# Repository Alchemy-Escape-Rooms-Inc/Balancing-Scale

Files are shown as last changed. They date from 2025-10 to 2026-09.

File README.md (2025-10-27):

# BALANCING SCALE
A pendulum scale that is part of the pirate shiproom prop.
It is used to measure the weight of the different items in the puzzle.
The scale is using RFID technology to determine the pre-designated items
that are placed on the scale(plates), rather than measuring the actual weight. 
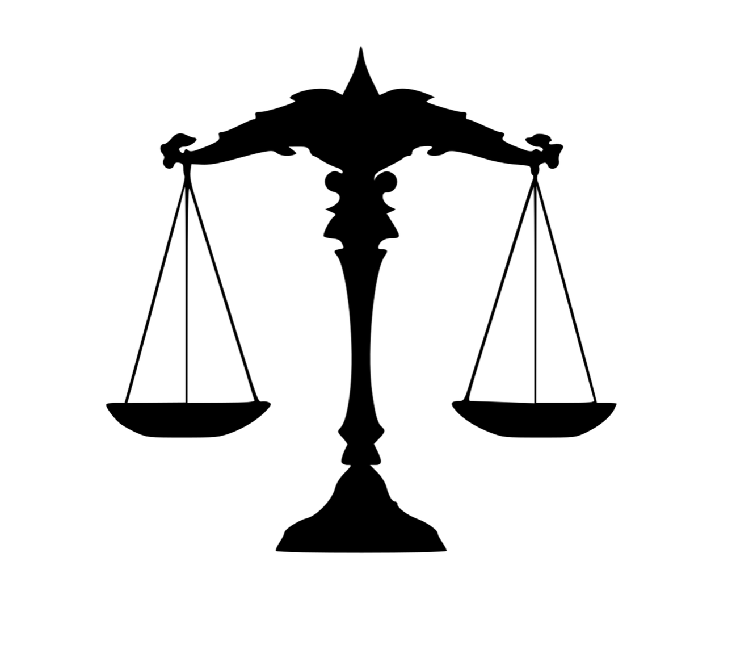
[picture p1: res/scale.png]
Scale


## RFID Readers
 The RFID readers used in this setup are two [ID-12LA](https://www.digikey.com/en/products/detail/sparkfun-electronics/11827/7364971); one for each plate. They are 125kHz RFID reader modules by ID-innovations and can be sourced most notibly from [DigiKey](https://www.Digikey.com) and [Sparkfun](https://www.sparkfun.com/).
The corresponding cards, stickers, fobs, etc. to be used with this reader must be 125kHz compatible to get a proper response from the reading module.
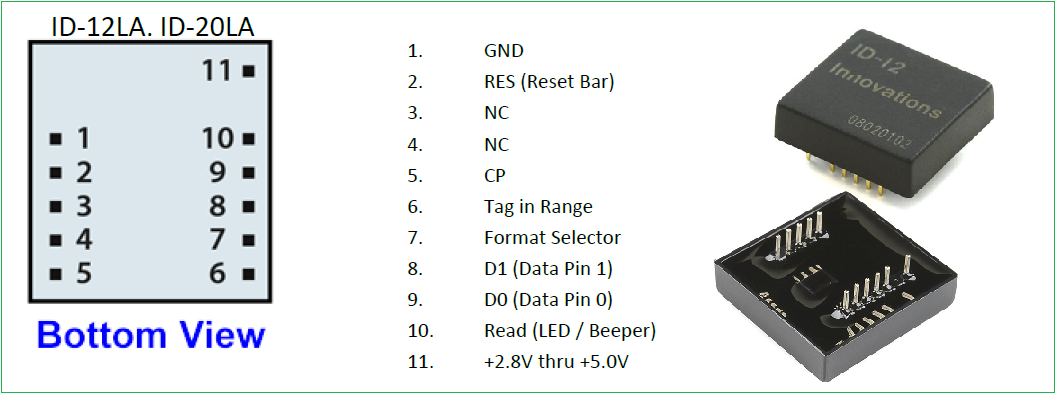
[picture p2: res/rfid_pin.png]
rfid


## Controller
The controller for this setup is the Arduino Nano. Its small compact size allow for it to conveniently be placed inside the scale's drawer. It is responsible for gathering and processing the information from the RFID readers.</br>
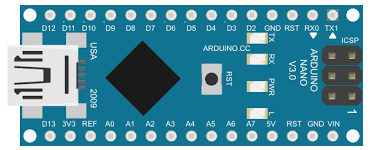
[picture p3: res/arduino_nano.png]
arduino


## Breakout Board
A custom printed circuit board that was designed to receive the 2mm pitch pins from the RFID reader and provide a few additional pins to connect with the reader.</br>
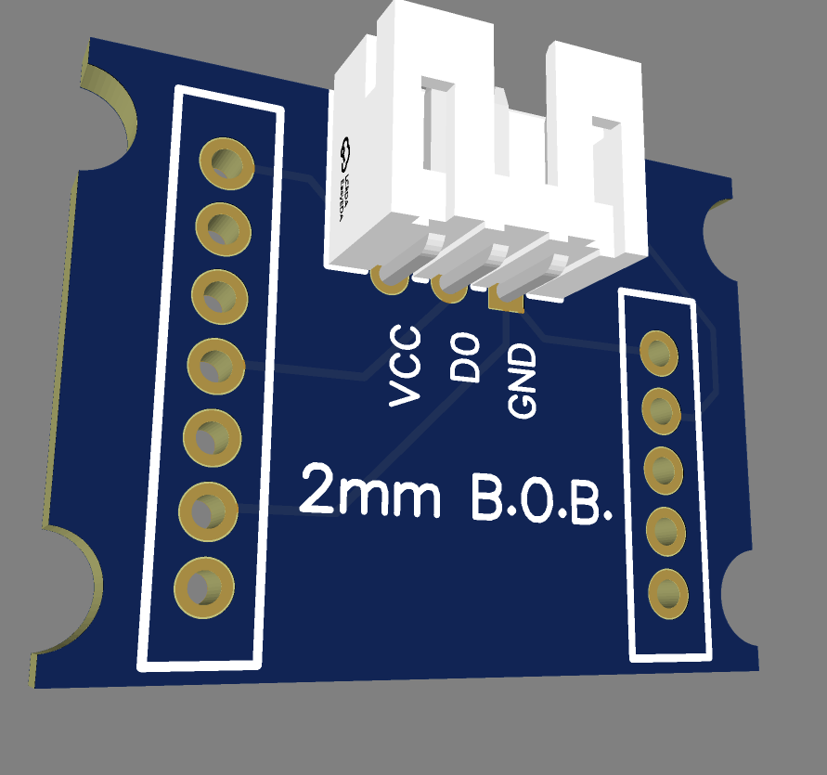
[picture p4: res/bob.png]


## 3D Models
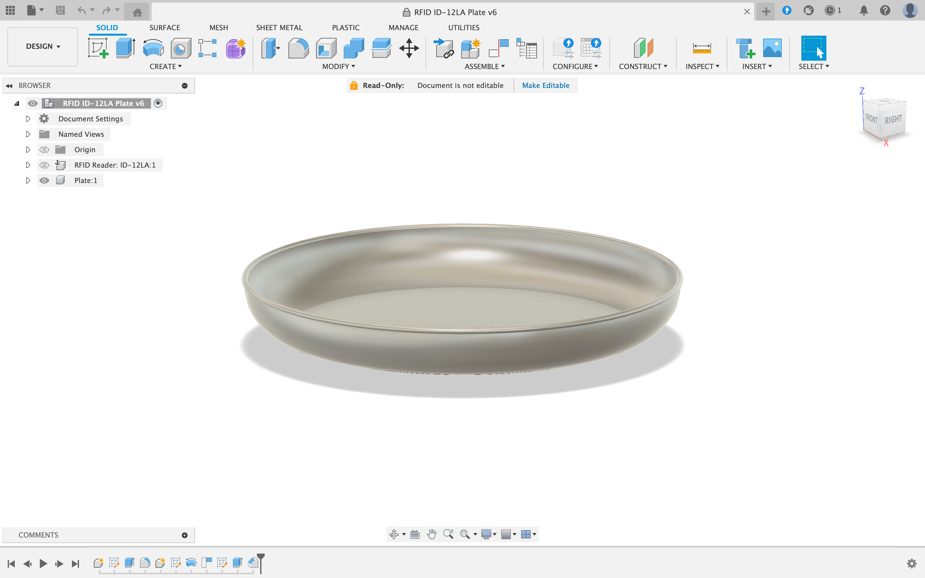
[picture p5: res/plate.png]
Plate
The RFID reader is uncapable of properly broadcasting a signal through metal plates; therefore a 3D model was designed to be used. Within the plate design, a guide for the RFID cover housing was attached underneath the plate. The RFID readers while being placed under the plates, should not be exposed, therefore a cover housing was designed. They are connected to the plate using screws.

## Algorithm
1. Plate 1 Listen for any rfid transmitter near by.
2. If there is no rfid being scanned, leave the sub routine. 
3. If there is a rfid in range, take the value and store 
it in a temporary variable. 
4. Check if the value is a valid pre-designated ID. 
5. If it is not a valid ID, leave the sub routine.
6. If it is a valid ID, check if it was already stored for 
the corresponding plate. 
7. If it was already stored, leave the sub routine. 
8. If it was not already stored, store the new ID for the 
corresponding plate.
9. Follow the same steps from 1-8 for plate 2. 
10. Check for any succession. 
11. If there was a succession, illuminate the green LED,
otherwise maintain the red LED.
12. Go back to step 1.

## Connections
There are a total of 3 modules in the Balancing Scale. Two rfid reader modules and an Arduino Nano. The ID-12LA rfid reader modules, is configured to output ASCII format via the D0 pin, when the FORMAT pin is tied to ground. The reset pin on the reader modules is tied to the supply voltage. The power connections (Vsupply and GND) to the rfid reader modules comes from the Arduino Nano. The D0 pins from the reader modules both get their own pin on the Arduino Nano. An RGB LED is added as an indicator. The red and green leads of the LED is tied via 1k resistors to the Arduino Nano. And, the final connection is the power to Arduino Nano comes in via the USB port.
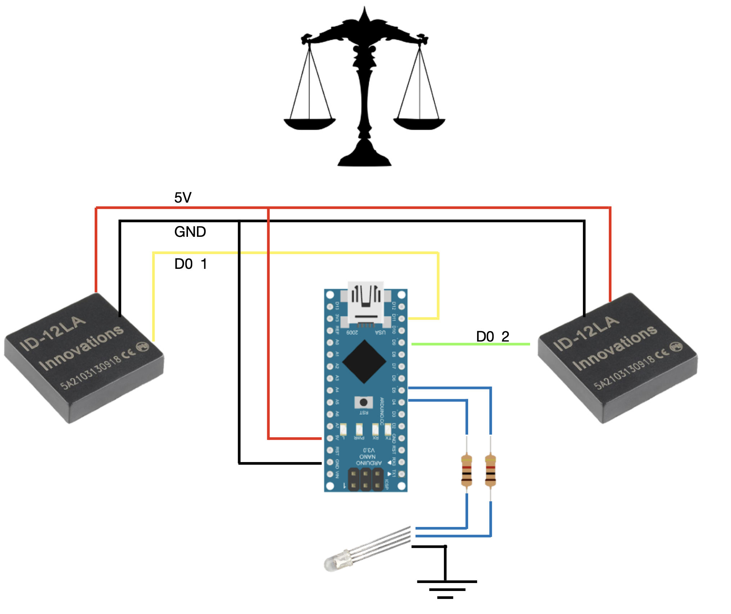
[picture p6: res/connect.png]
connections


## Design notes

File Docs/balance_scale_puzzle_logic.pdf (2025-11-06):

# Pirate Balancing Scale Puzzle

Logic Map & System Design

## Puzzle Overview

Players must balance five different spice pouches using gold coins of various denominations. The scale appears to be a traditional balance scale from the 1600s pirate era, but uses RFID technology to detect correct combinations. A compass indicator provides period-authentic feedback.

## Physical Components

Component | Description | Technology
Balance Scale | Two-plate traditional scale (theatrical) | Display prop
Spice Pouches | 5 pouches with different weights | RFID tags embedded
Gold Coins | 3 denominations with weights printed | RFID tags embedded
Compass Indicator | Points to "Aye" or "Nay" | Servo motor controlled
Left RFID Reader | Detects spice pouch | RC522 or PN532
Right RFID Reader | Detects coin combination | RC522 or PN532
ESP32 Controller | Processes logic and controls servo | ESP32-S3

## Weight Configuration

Spice Pouch | Weight | RFID Tag | Required Coins
Pouch 1 | 1.5g | Tag 112 | 1g + 0.5g or 0.75g + 0.75g
Pouch 2 | 1.75g | Tag 113 | 1g + 0.75g or 0.5g + 0.5g + 0.75g
Pouch 3 | 2.25g | Tag 114 | 1g + 1g + 0.25g or 0.75g + 0.75g + 0.75g
Pouch 4 | 3.5g | Tag 115 | 1g + 1g + 1g + 0.5g or various combos
Pouch 5 | 4.0g | Tag 116 | 1g + 1g + 1g + 1g
Coin Type | Weight | RFID Tag Range
Gold Doubloon | 1.0g | Tags 200-210

Half Doubloon | 0.5g | Tags 211-220
Piece of Eight | 0.75g | Tags 221-230
Quarter Doubloon | 0.25g | Tags 231-240

## System Logic Flow

1. System continuously monitors left RFID reader for spice pouch detection
2. When spice pouch is detected, system retrieves the target weight from lookup table
3. System continuously monitors right RFID reader for coin tags
4. System calculates total weight of detected coins based on their RFID tags
5. System compares calculated coin weight to required spice pouch weight
6. If weights match: Servo rotates compass from 'Nay' to 'Aye' position
7. If weights don't match: Compass remains at 'Nay' position
8. When spice pouch is removed from left reader: Servo resets compass to 'Nay' position
9. System returns to step 1 (ready for next attempt)

## System States

State | Condition | Compass Position | Action
IDLE | No spice pouch detected | Nay | Monitor left reader
DETECTING | Spice pouch on left | Nay | Monitor right reader & calculate
BALANCED | Correct coin combo | Aye | Hold until pouch removed
RESET | Pouch removed | Nay | Return to IDLE

## Hardware Connections

ESP32-S3 Pin Configuration:

Component | ESP32 Pin | Notes
Left RFID SDA | GPIO 21 | I2C or SPI depending on reader
Left RFID SCL | GPIO 22 | I2C or SPI clock
Right RFID SDA | GPIO 18 | Second I2C/SPI bus or different CS pin
Right RFID SCL | GPIO 19 | Second I2C/SPI clock
Servo Signal | GPIO 25 | PWM capable pin
Power (5V) | 5V | For RFID readers and servo

Ground | GND | Common ground for all components

## Programming Logic Overview

Data Structures:

Spice Pouch Lookup Table: Maps RFID tag IDs to weight values in grams

Coin Weight Lookup Table: Maps RFID tag ID ranges to coin weights

State Variables: Current spice pouch detected, calculated coin weight, compass position

Main Program Loop:

- Read left RFID reader for spice pouch tag
- If spice pouch detected:
- Look up required weight
- Read all tags from right RFID reader
- Calculate total weight of coins
- Compare weights
- Update compass position via servo
- If no spice pouch detected:
- Reset compass to 'Nay' position
- Delay 100-200ms before next loop iteration

## Compass Servo Control

Position | Angle | PWM Value | Meaning
Nay | 0° | ~1000µs pulse | Incorrect or no attempt
Aye | 90° | ~1500µs pulse | Correct balance achieved

## Player Experience Flow

1. Players discover five spice pouches and various gold coins with weights printed on them
2. Players place a spice pouch on the left side of the balance scale
3. Players experiment with different coin combinations on the right side

4. When correct total weight is achieved, compass dramatically spins to 'Aye'
5. Players note the successful combination and remove the spice pouch
6. Compass resets to 'Nay', ready for the next spice pouch
7. Players repeat process for all five spice pouches
8. Once all five combinations are discovered, the puzzle is complete

## Implementation Notes

- RFID readers should be concealed beneath or within the scale plates
- Servo motor should be hidden behind compass display
- Consider adding sound effects (creaking wood, wind) when compass moves
- Test RFID read range to ensure reliable detection through scale materials
- Multiple coins of same denomination should be supported (same weight, different tags)
- Consider adding a 'tolerance' margin if using actual weight sensors as backup
- Compass movement should be smooth and deliberate (not jerky) for theatrical effect
- System should debounce RFID readings to prevent flickering between states

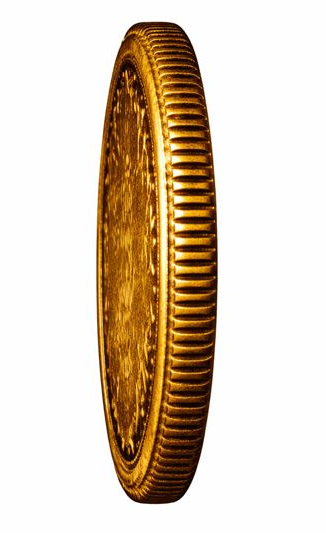
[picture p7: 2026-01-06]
3DFiles/2D/coins/side 1.png

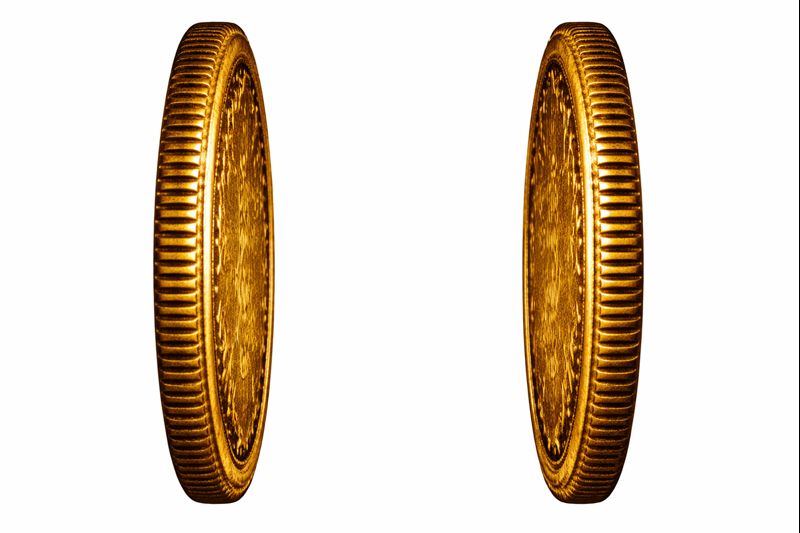
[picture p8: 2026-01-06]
3DFiles/2D/coins/sides.jpeg

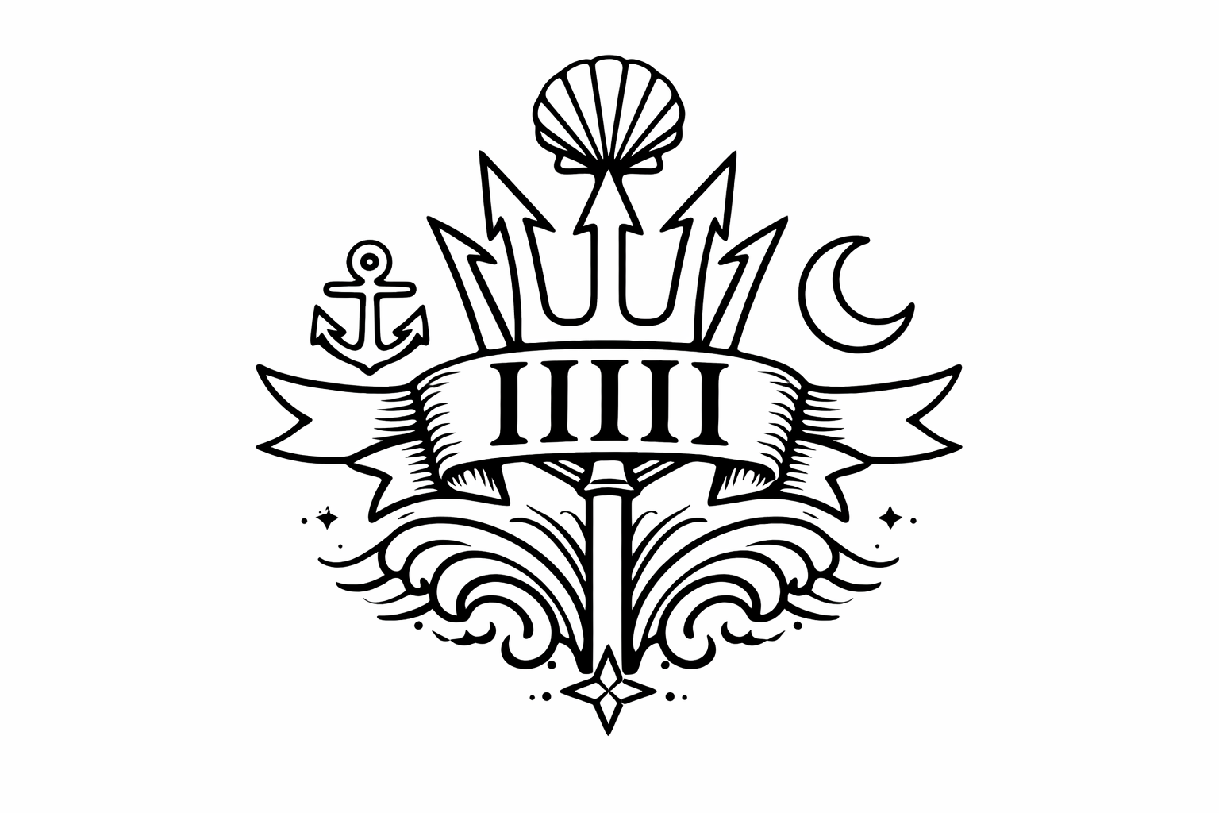
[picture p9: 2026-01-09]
3DFiles/2D/coins/generated/ChatGPT Image Jan 9, 2026, 08_28_24 AM.png

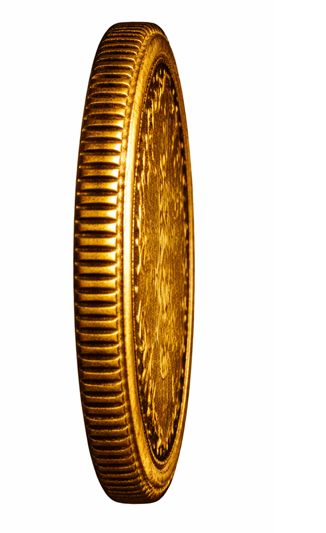
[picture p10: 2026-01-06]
3DFiles/2D/coins/side 2.png

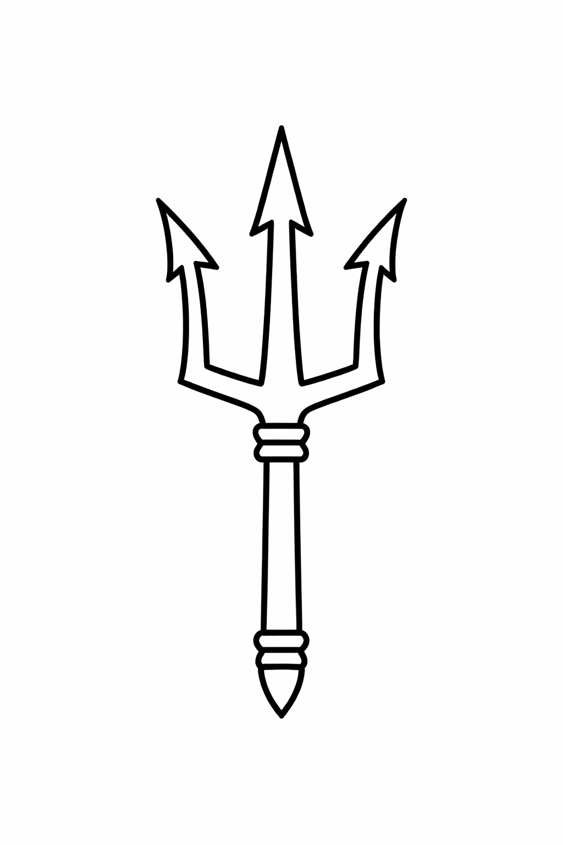
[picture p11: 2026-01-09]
3DFiles/2D/coins/generated/ChatGPT Image Jan 9, 2026, 08_28_42 AM.png

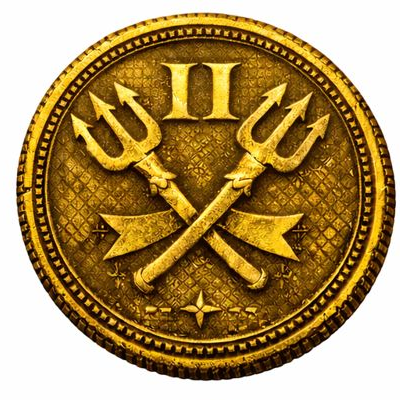
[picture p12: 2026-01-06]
3DFiles/2D/coins/Coin 2.png

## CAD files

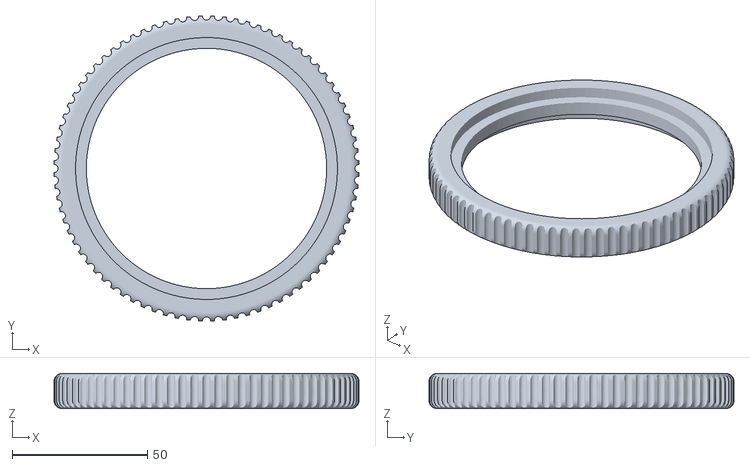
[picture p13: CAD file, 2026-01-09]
3DFiles/STL/Coins/Coin Ring.stl
113.0 x 113.0 x 13.0

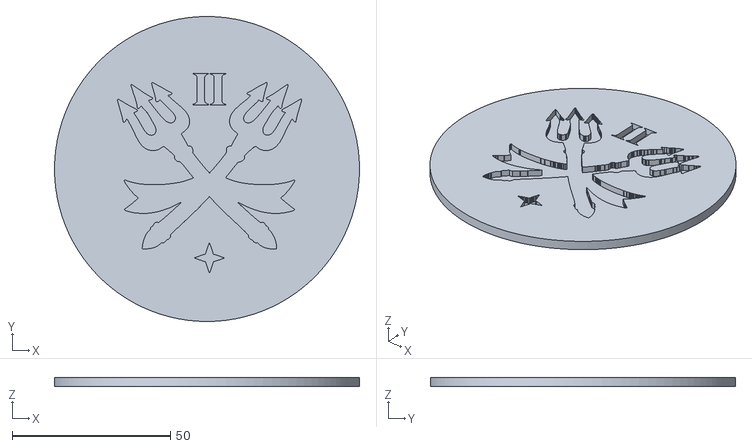
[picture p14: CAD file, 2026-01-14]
3DFiles/STL/Coins/v3/Crossing Tridents.stl
96.4 x 96.4 x 3.00

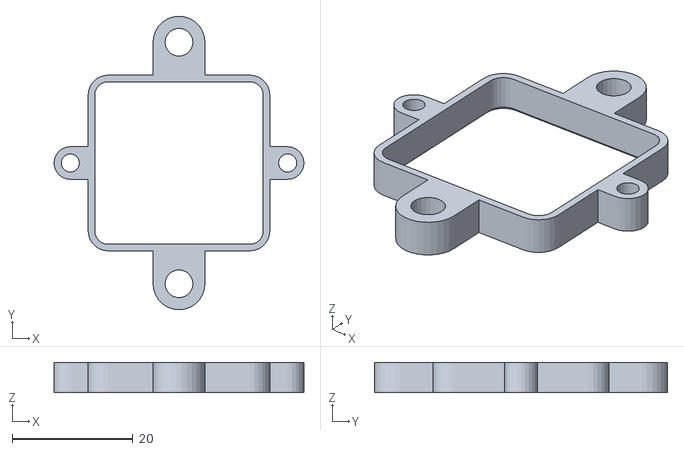
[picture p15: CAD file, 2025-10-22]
3DFiles/STL/RFID Reader/RFID ID-12LA Plate Mount.stl
41.4 x 48.6 x 5.00

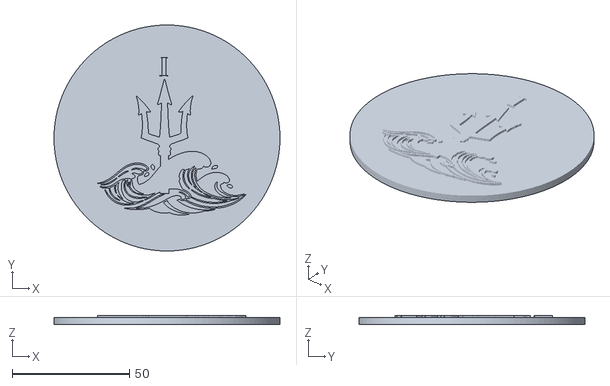
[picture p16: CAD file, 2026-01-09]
3DFiles/STL/Coins/Coins Face 1.stl
96.4 x 96.4 x 4.00

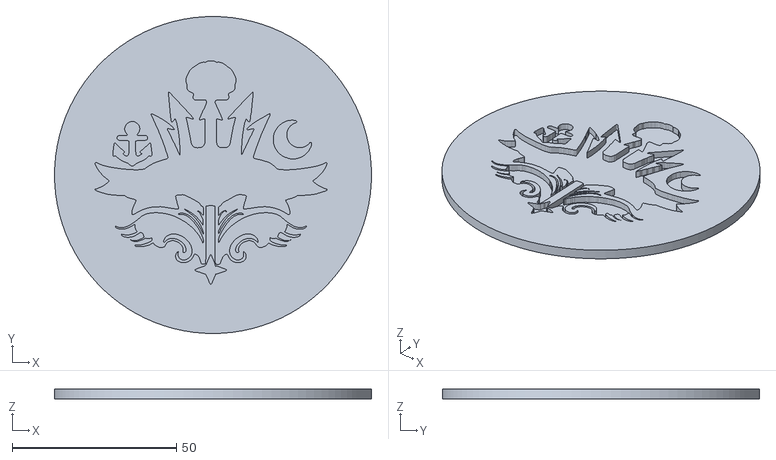
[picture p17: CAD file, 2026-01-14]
3DFiles/STL/Coins/v3/Emblem Trident.stl
96.4 x 96.4 x 3.00

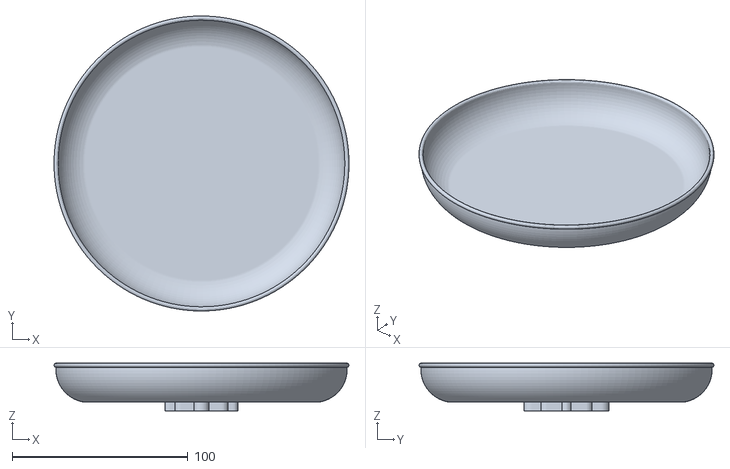
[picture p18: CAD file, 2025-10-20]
3DFiles/STL/RFID Reader/RFID ID-12LA Plate.stl
168.0 x 168.0 x 27.2

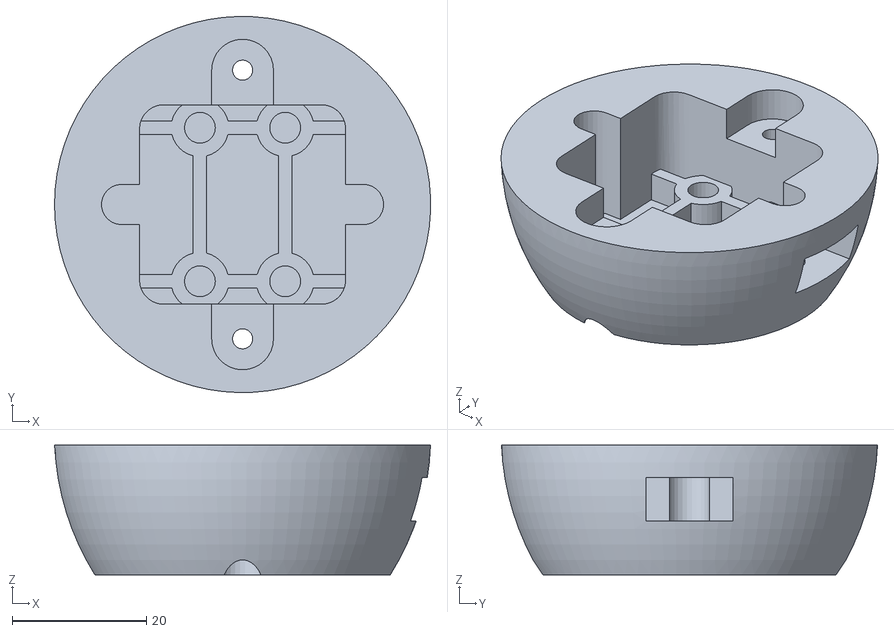
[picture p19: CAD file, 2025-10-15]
3DFiles/STL/RFID Reader/RFID ID-12LA Housing.stl
56.0 x 56.0 x 19.3

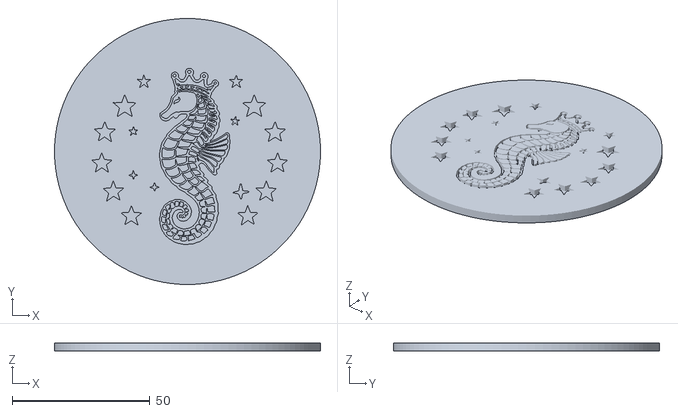
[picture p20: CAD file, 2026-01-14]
3DFiles/STL/Coins/v3/Seahorse.stl
96.4 x 96.4 x 3.00

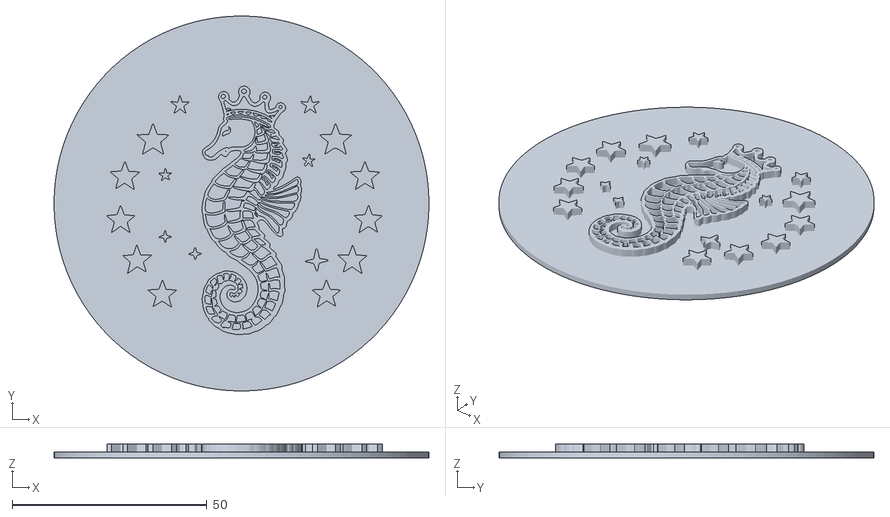
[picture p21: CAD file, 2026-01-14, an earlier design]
3DFiles/STL/Coins/v2/Seahorse.stl
96.4 x 96.4 x 3.50

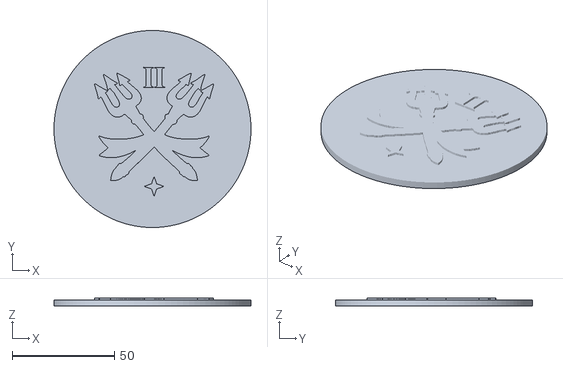
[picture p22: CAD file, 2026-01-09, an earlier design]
3DFiles/STL/Coins/v1/Coin Face 2.stl
96.4 x 96.4 x 4.00

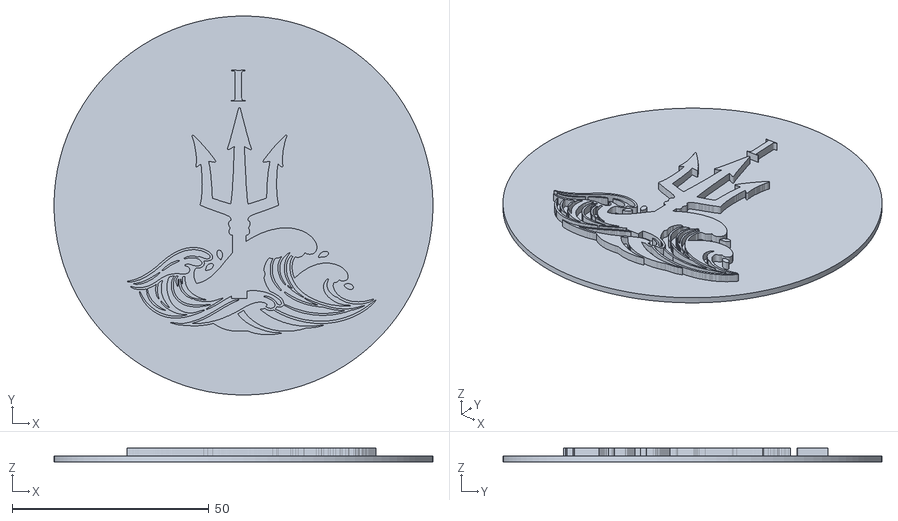
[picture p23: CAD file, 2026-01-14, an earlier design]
3DFiles/STL/Coins/v2/Waves Trident.stl
96.4 x 96.4 x 3.50

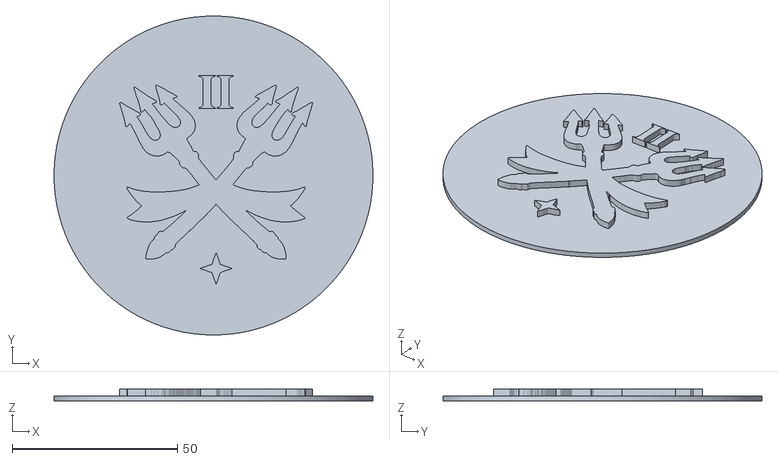
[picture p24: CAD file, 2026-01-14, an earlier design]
3DFiles/STL/Coins/v2/Crossing Trident.stl
96.4 x 96.4 x 3.50

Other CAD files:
3DFiles/STL/Coins/v3/Waves Trident.stl
3DFiles/STL/Coins/v3/Stars Trident.stl
3DFiles/STL/Coins/v1/Coin Face 4.stl
3DFiles/STL/Coins/v1/Coin Face 5.stl
3DFiles/STL/Coins/v2/Star Trident.stl
3DFiles/STL/Coins/v1/Coin Face 3.stl
3DFiles/Fusion360/RFID ID-12LA Housing.f3d
3DFiles/Fusion360/RFID ID-12LA Plate.f3d
3DFiles/STL/Coins/v2/Emblem Trident.stl

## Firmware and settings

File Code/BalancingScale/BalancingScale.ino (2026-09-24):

//=============================================================
//                        MACROS
//=============================================================
#pragma once

#include <WiFi.h>
#include <PubSubClient.h>
#include <HardwareSerial.h>
#include <ESP32Servo.h>
#include <ArduinoOTA.h>   // mandatory fleet protocol (2026-09-22): wireless re-flash

#define VERSION "1.4.0"

#define GAME_NAME "MermaidsTale"
#define PROP_NAME "BalancingScale"

#define MQTT_TOPIC          "MermaidsTale/BalancingScale"
#define MQTT_TOPIC_COMMAND  "MermaidsTale/BalancingScale/command"
#define MQTT_TOPIC_STATUS   "MermaidsTale/BalancingScale/status"
#define MQTT_TOPIC_LOG      "MermaidsTale/BalancingScale/log"
#define MQTT_TOPIC_MESSAGE  "MermaidsTale/BalancingScale/message"
#define MQTT_TOPIC_SYSTEM   "MermaidsTale/BalancingScale/system"


#define NUM_OF_SPICE_POUCHES 5
#define NUM_OF_COINS 8
#define SERVO_PIN 13

#define RX1 18
#define TX1 19

#define RX2 16
#define TX2 17
#define BAUD_RATE 115200
#define ID_LENGTH 4
#define MAX_READABLE 5                //RFIDs can only read 5 tags at once.

WiFiClient espClient;
PubSubClient mqttClient(espClient);
//=============================================================
//                      DATA STRUCTURE(S)
//=============================================================

/**
 * @brief A struct/container for holding a pair of values,
 *        the RFID(ID) and the represented weight.
 * @tparam N The maximum number of elements to
 *           represent the ID received from the RFID.
 */

template<byte N>
struct IDStorage {
  float weight;       //Represented weight of the RFID object.
  byte id[ID_LENGTH]; //ID of the RFID object.

  /**
   * @brief Default constructor, which initialize all values to 0.
   */
  IDStorage()
    : weight(0.0), id{ 0, 0, 0, 0 } {}
  /**
   * @brief Constructor, which initialize the members using
   *        the arguments.
   * @param vWeight Weight value to be assign to RFID the
   *                object.
   * @param &vID A constant array of char literals of size N.
   */
  IDStorage(float vWeight, const byte (&vID)[N])
    : weight(vWeight) {
      for (int i = 0; i < ID_LENGTH; i++)
        id[i] = vID[i];
    }

  /**
   * @brief Constructor, which initialize the members using
   *        the arguments.
   * @param vWeight Weight value to be assign to RFID object.
   * @param vID An array of char.
   */
  /*
     IDStorage(float vWeight,const char vID[]):weight(vWeight) {
     for (int i = 0; i < ID_LENGTH; i++)
     id[i] = vID[i];
     }
     */
};

//COINS
/**
 * @brief A derived struct of the IDStorage struct to
 *        hold values specifically for the RFID coins
 *        object demonations.
 * @tparam N The maximum number of elements to
 *           represent the ID received from the RFID.
 */
template<byte N>
struct Coin : IDStorage<N> {
  /**
   * @brief Constructor, which initialize the members using
   *        the arguments.
   * @param vWeight Weight value to be assign to the RFID
   *                object.
   * @param &vID A constant array of char literals of size N.
   */
  Coin(float vWeight, const byte (&vID)[N])
    : IDStorage<N>(vWeight, vID) {}
};

template<byte N>
struct GoldDoubloon : Coin<N> {
  GoldDoubloon(const byte (&vID)[N])
    : Coin<N>(1.0, vID) {}
};
template<byte N>
struct HalfDoubloon : Coin<N> {
  HalfDoubloon(const byte (&vID)[N])
    : Coin<N>(0.5, vID) {}
};
template<byte N>
struct PieceOfEight : Coin<N> {
  PieceOfEight(const byte (&vID)[N])
    : Coin<N>(0.75, vID) {}
};
template<byte N>
struct QuarterDoubloon : Coin<N> {
  QuarterDoubloon(const byte (&vID)[N])
    : Coin<N>(0.25, vID) {}
};

//POUCH
template<byte N>
struct Pouch : IDStorage<N> {
  String spice;
  Pouch(float vWeight, const byte (&vID)[N]):IDStorage<N>(vWeight, vID) {}
  Pouch(const String & vSpice, float vWeight, const byte (&vID)[N]):spice(vSpice),IDStorage<N>(vWeight, vID){}
};

//PLATES

/**
 * @brief A struct/container to hold a few values, for
 *        keeping track of the RFID objects placed on the
 *        scale's plates.
 * @tparam N The maximum number of IDs that can stored for
 *           this struct's object.
 */
template<byte N>
struct ScalePlates {
  IDStorage<ID_LENGTH> storage[N];  //An array of the IDs stored
  byte index = 0;                   //Value to keep track of the amount of stored IDs
  float plateWeight = 0.0;          //Represents the total amount of RFID objects placed on the scale's plate.

  /**
   * @brief Adds a new RFID object to the storage.
   * @param vWeight Weight value of the RFID object.
   * @param vID The ID of the RFID object.
   */
  void addNewStorage(float vWeight,const byte (&vID)[ID_LENGTH]){
    if((index + 1) > N)
      return;
    storage[index] = IDStorage<ID_LENGTH>(vWeight,vID);
    plateWeight += vWeight;
    index++;
  }

  /**
   * @brief Removes a RFID object from the storage.
   * @param rIndex Index of RFID object that is to be
   *               removed from the storage.
   */
  void removeStorage(int rIndex){
    if((index-1) < 0)
      return;
    float weight = storage[rIndex].weight;
    shiftStorageLeft(rIndex);
    clearStorage(index-1);
    plateWeight -= weight;
    index--;
  }

  /**
   * @brief Shifts all the RFID object information in
   *        the array storage to the left overriding
   *        one of stored objects.
   * @param sIndex Index of the stored object to be
   *               overriden by the left shift.
   */
  void shiftStorageLeft(int sIndex){
    for(int i = sIndex; i < index; i++){
      for(int j = 0; j < ID_LENGTH; j++){
        if((i + 1) != index)
          storage[i].id[j] = storage[i+1].id[j];
      }
      if((i + 1) != index)
        storage[i].weight = storage[i+1].weight;
    }
  }

  /**
   * @brief Clears/Sets all the RFID object information
   *        to 0.
   * @param cIndex Index of the stored object information
   *               to be cleared.
   */
  void clearStorage(int cIndex){
    for(int i  = 0; i < ID_LENGTH; i++)
      storage[cIndex].id[i] = 0;
    storage[cIndex].weight = 0.0;
  }


  void printStorage(){

    //if(index <= 0)
    //  return;
    /*
       for(int i = 0; i < index; i++){

       String uid = "";
       for(int j = 0; j < ID_LENGTH; j++)
       uid += String(storage[i].id[j],HEX) + String((j == ID_LENGTH-1) ? "":"-");

       mqttClient.publish(String(String(MQTT_TOPIC_SYSTEM) + "/storedUID" + String(i)).c_str(),uid.c_str());

       }
       */
    mqttClient.publish(String(String(MQTT_TOPIC_SYSTEM) + "/storedWeight").c_str(),String(plateWeight).c_str());
    mqttClient.publish(String(String(MQTT_TOPIC_SYSTEM) + "/storedIndex").c_str(),String(index).c_str());
  }
};

//=============================================================
//                      GLOBAL VARIABLES
//=============================================================

byte CMD_GET_TAG_COUNT[] = { 0xF5, 0x03, 0x00, 0xFC, 0xFF, 0x02, 0xB2, 0xC1 };
byte CMD_HALT[] = { 0xF5, 0x03, 0x00, 0xFC, 0xFF, 0x05, 0x55, 0xB1 };
byte CMD_REBOOT[] = { 0xF5, 0x03, 0x00, 0xFC, 0xFF, 0x0A, 0xBA, 0x40 };
byte CMD_DUMMY[] = { 0xF5, 0x03, 0x00, 0xFC, 0xFF, 0x01, 0xD1, 0xF1 };
byte CMD_GET_UID[5][9] = {
  { 0xF5, 0x04, 0x00, 0xFB, 0xFF, 0x03, 0x00, 0x5C, 0x48 },
  { 0xF5, 0x04, 0x00, 0xFB, 0xFF, 0x03, 0x01, 0x7D, 0x58 },
  { 0xF5, 0x04, 0x00, 0xFB, 0xFF, 0x03, 0x02, 0x1E, 0x68 },
  { 0xF5, 0x04, 0x00, 0xFB, 0xFF, 0x03, 0x03, 0x3F, 0x78 },
  { 0xF5, 0x04, 0x00, 0xFB, 0xFF, 0x03, 0x04, 0xD8, 0x08 }
};

Servo mServo;
HardwareSerial rfid1(1);
HardwareSerial rfid2(2);



byte uid[ID_LENGTH * MAX_READABLE];


const char* WIFI_SSID = "AlchemyGuest";
const char* WIFI_PASS = "VoodooVacation5601";
const char* OTA_PASSWORD = WIFI_PASS;   // protocol: OTA password = Wi-Fi password
#define OTA_HOSTNAME PROP_NAME          // protocol: hostname = DEVICE_NAME
#define OTA_PORT     3232               // classic ESP32 default

// MQTT broker
const char* MQTT_SERVER = "10.1.10.115";
const int MQTT_PORT = 1883;

bool servoState = false;    //true = yay, false = nay

float weights[5];     //array to hold the spices weight
bool success[5] = {false,false,false,false,false}; //array for tracking the correct spice pouch solved

bool puzzleSolved = false;

String incoming = "";


const unsigned long heartBeatPulse = 300 * 1000UL;  //heart beat for MQTT, every 5 minutes (WatchTower standard)
const unsigned long scanPeriod = 1000UL;      //scanning of the RFIDs and other associated operations, every second

unsigned long hLastTime = 0;
unsigned long sLastTime = 0;

//Known IDs for the pouches and their represented weights.
const Pouch<ID_LENGTH> sPouches[NUM_OF_SPICE_POUCHES] = {

  Pouch<ID_LENGTH>("Yeast",2.5f, (byte []){0xC1, 0x27, 0xFB,0x19}),
  Pouch<ID_LENGTH>("SugarCane",2.25f,  (byte []){0x60, 0x74, 0x15,0x21}),
  Pouch<ID_LENGTH>("Vanilla",1.75f,  (byte []){0x94, 0xD3, 0xC9,0x1}),
  Pouch<ID_LENGTH>("Molasses",2.75f,  (byte []){0x80, 0x1E, 0x7C,0x21}),
  Pouch<ID_LENGTH>("Cloves",1.5f,  (byte []){0x71, 0xD, 0xEB,0x17})
};

//Known IDs for the coins and their represented weights.
//ROOM NAMES (owner, 2026-09-10) - the players' rules call these coins:
//  GoldDoubloon    = "gold"   = 1.00
//  PieceOfEight    = "silver" = 0.75   (NOT a historical piece of eight - a puzzle value)
//  HalfDoubloon    = "copper" = 0.50
//  QuarterDoubloon = "bronze" = 0.25
//The struct names below are the contractor's; the values are what the scale
//checks. Two coins of each type. A plate reads at most MAX_READABLE tags.
const Coin<ID_LENGTH> coins[NUM_OF_COINS] = {
  //example of initialization of coins
  GoldDoubloon<ID_LENGTH>({0x80, 0xD5, 0xCF,0x21}),
  GoldDoubloon<ID_LENGTH>({0x31, 0x61, 0x86,0x26}),
  HalfDoubloon<ID_LENGTH>({0x1B,0xF,0x39,0x6}),
  HalfDoubloon<ID_LENGTH>({0x19,0xF0,0x4F,0x6}),
  PieceOfEight<ID_LENGTH>({0x81,0xE8,0x50,0x6}),
  PieceOfEight<ID_LENGTH>({0xF1,0x76,0xC3,0x1}),
  QuarterDoubloon<ID_LENGTH>({0xE2,0x52,0xE3,0x19}),
  QuarterDoubloon<ID_LENGTH>({0x62,0xC7,0x38,0x6})
};

//Objects to store the detected tag IDs based on their type.
ScalePlates<NUM_OF_COINS> coinsPlate;
ScalePlates<NUM_OF_SPICE_POUCHES> pouchesPlate;

//=============================================================
//                    NETWORK & MQTT
//=============================================================

//WIFI NETWORK
void setupWiFi() {
  delay(1000);
  Serial.println("*********** WIFI ***********");
  Serial.print("Connecting to SSID: ");
  Serial.println(WIFI_SSID);

  WiFi.begin(WIFI_SSID,WIFI_PASS);

  while(WiFi.status() != WL_CONNECTED){
    delay(100);
    Serial.print("-");
  }
  Serial.println("\nConnected.");
  Serial.print("IP: "); Serial.print(WiFi.localIP());
  Serial.print("  GW: "); Serial.print(WiFi.gatewayIP());
  Serial.print("  RSSI: "); Serial.println(WiFi.RSSI());
}

/**
 * @brief Over-the-air update listener (fleet protocol, mandatory since
 *        2026-09-22). hostname = BalancingScale, port 3232, password = Wi-Fi.
 *        Flash wirelessly with:
 *          arduino-cli upload --fqbn esp32:esp32:esp32 -p <board IP>
 *              --upload-field password=<Wi-Fi pw> Code/BalancingScale
 *        The IP is in every STATUS reply and the boot line on /log.
 *        No task WDT on this board, so nothing to feed during upload.
 */
void setupOTA() {
  ArduinoOTA.setHostname(OTA_HOSTNAME);
  ArduinoOTA.setPassword(OTA_PASSWORD);
  ArduinoOTA.onStart([]() {
    // Only actuator is the indicator servo - park it so it is not mid-swing
    // on the reboot. Readers just stop being polled.
    servoMid();
    mqttLogf("OTA update starting - scale holds, back in ~30 s");
    mqttClient.loop();
  });
  ArduinoOTA.onEnd([]()   { Serial.println("OTA done, rebooting"); });
  ArduinoOTA.onError([](ota_error_t e) { Serial.printf("OTA error %u\n", (unsigned)e); });
  ArduinoOTA.begin();
  Serial.printf("OTA ready: %s @ %s:%d\n", OTA_HOSTNAME, WiFi.localIP().toString().c_str(), OTA_PORT);
}

//MQTT SERVER
void connectMQTT() {
  while (!mqttClient.connected()) {
    Serial.print("Connecting to MQTT...");

    String clientId = PROP_NAME;
    clientId += "_";
    clientId += String(random(0xffff), HEX);

    // LWT: broker publishes retained OFFLINE on /status if we drop
    if (mqttClient.connect(clientId.c_str(), MQTT_TOPIC_STATUS, 1, true, "OFFLINE")) {
      Serial.println("connected!");

      // Subscribe to command topic
      mqttClient.subscribe(MQTT_TOPIC_COMMAND);

      // Announce we're online
      mqttClient.publish(MQTT_TOPIC_STATUS, "ONLINE", true);
      mqttLogf("%s v%s online IP:%s OTA:%d RSSI:%d", PROP_NAME, VERSION,
               WiFi.localIP().toString().c_str(), OTA_PORT, WiFi.RSSI());

    } else {
      Serial.printf("failed (rc=%d), retrying in 5s\n", mqttClient.state());
      // Keep the OTA listener alive while the broker is down so a bad
      // build that cannot reach MQTT can still be replaced wirelessly.
      for (int i = 0; i < 50; i++) { ArduinoOTA.handle(); delay(100); }
    }
  }
}

void mqttCallback(char* topic, byte* payload, unsigned int length) {
  char topicBuf[128];
  strncpy(topicBuf,topic,sizeof(topicBuf)-1);
  topicBuf[sizeof(topicBuf)-1] = '\0';

  char message[128];
  if(length >= sizeof(message)){
    length = sizeof(message) - 1;
  }

  memcpy(message,payload,length);
  message[length] = '\0';

  char * msg = message;
  while(*msg == ' ' || *msg == '\r' || *msg == '\n')
    msg++;
  char * end = msg + strlen(msg) -1;
  while(end > msg && (*end == ' ' || *end == '\t' || *end == '\r' || *end == '\n')){
    *end = '\0';
    end--;
  }

  //Serial.printf("[MQTT] Received on %s: %s\n", topicBuf,msg);

  if(strcmp(topicBuf,MQTT_TOPIC_COMMAND) != 0){
    return;
  }

  // Our own PONG/OK replies arrive back on /command (we subscribe to it).
  // Ignore them silently so they don't register as unknown commands.
  if(strcmp(msg,"PONG") == 0 || strcmp(msg,"OK") == 0 || strlen(msg) == 0){
    return;
  }

  if(strcmp(msg,"PING") == 0){
    // WatchTower standard: PONG on the topic the command arrived on
    mqttClient.publish(MQTT_TOPIC_COMMAND,"PONG");
    return;
  }
  if(strcmp(msg,"STATUS") == 0){
    publishDiagnostics();
    return;
  }
  if(strcmp(msg,"RESET") == 0){
    // WatchTower standard: respond OK, then software reboot
    mqttLogf("RESET: rebooting");
    mqttClient.publish(MQTT_TOPIC_COMMAND,"OK");
    mqttClient.loop();
    delay(250);
    ESP.restart();
    return;
  }
  if (strcmp(msg, "PUZZLE_RESET") == 0) {
    // Reset game state without rebooting
    puzzleReset();
    mqttClient.publish(MQTT_TOPIC_COMMAND, "OK");
    return;
  }
  if (strcmp(msg, "SOLVE") == 0) {
    // GM override: mark the puzzle solved
    puzzleSolved = true;
    updateServo(true);
    publishSolved();
    return;
  }

  if (strcmp(msg, "HALTCOIN") == 0) {
    haltReader(rfid2);
    mqttClient.publish(MQTT_TOPIC_MESSAGE, "Halting coins' plate rfid field.");
    return;
  }
  if (strcmp(msg, "HALTSPICE") == 0) {
    haltReader(rfid1);
    mqttClient.publish(MQTT_TOPIC_MESSAGE, "Halting spices' plate rfid field.");
    return;
  }
  if (strcmp(msg, "REBOOTCOIN") == 0) {
    rebootReader(rfid2);
    mqttClient.publish(MQTT_TOPIC_MESSAGE, "Rebooting coins' plate rfid.");
    delay(1000); //needs minimum 1 second boot time
    return;
  }
  if (strcmp(msg, "REBOOTSPICE") == 0) {
    rebootReader(rfid1);
    mqttClient.publish(MQTT_TOPIC_MESSAGE, "Rebooting spices' plate rfid.");
    delay(1000); //needs minimum 1 second boot time
    return;
  }
  mqttLogf("Unknown command: %s", msg);
}

/**
 * @brief Publishes SOLVED on /status. M3's "Balancing Scale Solved" event
 *        matches this exact payload and forwards MermaidsTale/ScaleSolved.
 *        Not retained: a retained SOLVED would replay into fresh sessions.
 */
void publishSolved(){
  mqttClient.publish(MQTT_TOPIC_STATUS, "SOLVED");
  mqttLogf("PUZZLE SOLVED");
}

/**
 * @brief Resets all game state without rebooting (PUZZLE_RESET).
 */
void puzzleReset(){
  puzzleSolved = false;
  for(int i = 0; i < 5; i++)
    success[i] = false;
  clearAllParameters();
  updateServo(false);
  mqttClient.publish(MQTT_TOPIC_STATUS, "ONLINE", true);
  mqttLogf("PUZZLE_RESET complete");
}

/**
 * @brief Publishes a full diagnostics string on /status (STATUS command).
 */
void publishDiagnostics(){
  int count = 0;
  for(int i = 0; i < 5; i++)
    if(success[i])
      count++;
  char diag[192];
  snprintf(diag, sizeof(diag),
    "%s v%s | State=%s | Spice=%.2f | Coins=%.2f | Matched=%d/5 | IP:%s | OTA:%d | RSSI=%d | UP%lus",
    PROP_NAME, VERSION,
    puzzleSolved ? "SOLVED" : "ONLINE",
    pouchesPlate.plateWeight, coinsPlate.plateWeight, count,
    WiFi.localIP().toString().c_str(), OTA_PORT, WiFi.RSSI(), millis() / 1000UL);
  mqttClient.publish(MQTT_TOPIC_STATUS, diag);
}

void setupMQTT() {
  mqttClient.setServer(MQTT_SERVER, MQTT_PORT);
  mqttClient.setCallback(mqttCallback);
  mqttClient.setBufferSize(512);  // Increase if needed
}

void heartBeat(){
  unsigned long currentTime = millis();
  if(!(currentTime - hLastTime > heartBeatPulse))
    return;
  hLastTime = currentTime;
  // WatchTower standard heartbeat format on /status
  char hb[64];
  snprintf(hb, sizeof(hb), "HEARTBEAT:%s:UP%lus:RSSI%d",
           puzzleSolved ? "SOLVED" : "ONLINE", millis() / 1000UL, WiFi.RSSI());
  mqttClient.publish(MQTT_TOPIC_STATUS, hb);
  // While solved, re-assert the plain SOLVED payload M3 matches on, in case
  // M3 restarted mid-game and missed the live solve event.
  if(puzzleSolved)
    mqttClient.publish(MQTT_TOPIC_STATUS, "SOLVED");
}

void mqttLogf(const char* format, ...) {
  char buffer[256];
  va_list args;
  va_start(args, format);
  vsnprintf(buffer, sizeof(buffer), format, args);
  va_end(args);

  mqttClient.publish(MQTT_TOPIC_LOG, buffer);
  //Serial.println(buffer);
}

//=============================================================
//                  MAIN FUNCTIONS
//=============================================================
//=============================================================
//                  MISC FUNCTIONS
//=============================================================

void setupServo(){
  mServo.setPeriodHertz(100);
  mServo.attach(SERVO_PIN, 500, 2400); 
}

/**
 * @brief This function rotates the angle to
 *        0 degrees. Representing Yay.
 */
void servoYay(){
  mqttClient.publish(String(String(MQTT_TOPIC_MESSAGE) + "/servo").c_str(),"yay");
  mServo.write(155);
}
/**
 * @brief This function rotates the angle to
 *        90 degrees. Representing Nay.
 */
void servoNay(){
  mqttClient.publish(String(String(MQTT_TOPIC_MESSAGE) + "/servo").c_str(),"nay");
  mServo.write(30);
}



void updateServo(bool state){
  if(state){
    if(state == servoState){
      return;
    }
    else{
      servoYay();
      servoState = state;
    }

  } else {

    if(state == servoState){
      return;
    }
    else{
      servoNay();
      servoState = state;
    }
  }
 mqttClient.publish(String(String(MQTT_TOPIC_MESSAGE) + "/ServoState").c_str(),(state) ? "true":"false");
}
void servoMid(){
   mqttClient.publish(String(String(MQTT_TOPIC_SYSTEM) + "/servo").c_str(),"center");
   mServo.write(70);
}
/**
 * @brief This function resets all the scale's stored
 *        data.
 */
void clearAllParameters(){
  for(int i = 0; i < coinsPlate.index; i++)
    coinsPlate.clearStorage(i);
  for(int i = 0; i < pouchesPlate.index; i++)
    pouchesPlate.clearStorage(i);

  coinsPlate.plateWeight = 0.0;
  pouchesPlate.plateWeight = 0.0;

  coinsPlate.index = 0;
  pouchesPlate.index = 0;
}

/**
 * @brief This function checks if the user has success
 *        balanced the weight with the items.
 */
void checkSuccess(){
  //no tags on a plate, or weights don't match: show nay and leave.
  //(only touch the servo here on an actual mismatch — writing nay
  //unconditionally made the servo flap nay->yay every scan while balanced)
  if(pouchesPlate.plateWeight == 0 || coinsPlate.plateWeight == 0
     || pouchesPlate.plateWeight != coinsPlate.plateWeight){
    updateServo(false);
    return;
  }

  //weights match, update servo to yay
  updateServo(true);

  //get the matching weight and update the success tracking array
  //(publish the per-pouch topic once, on the transition - not every scan)
  bool newSuccess = false;
  for(int i = 0; i < 5; i++){
    if(weights[i] == pouchesPlate.plateWeight && !success[i]){
      success[i] = true;
      newSuccess = true;
      printSuccessToMQTT(i);
    }
  }

  //count the successes
  int count = 0;
  for(int i = 0; i < 5; i++)
    if(success[i])
      count++;

  if(newSuccess)
    mqttClient.publish(String(String(MQTT_TOPIC_MESSAGE) + "/SuccessCount").c_str(),String(count).c_str());
  //if success count is 5, the prop puzzle is solved, and finished
  if(count >= 5 && !puzzleSolved){
    puzzleSolved = true;
    publishSolved();
  }
}

/**
 * @brief Verify if the array of chars are a match.
 *
 * This function verifies if the passed in IDs are
 * identical.
 *
 * @param id1 An array of char representing the RFID(ID).
 * @param id2 An array of char representing the RFID(ID).
 * @return A boolean value, whether both IDs are identical.
 */
bool isAMatchingID(const byte id1[], const byte id2[]) {
  for (int i = 0; i < ID_LENGTH; i++)
    if (id1[i] != id2[i])
      return false;
  return true;
}
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
void loop() {
  program();
}

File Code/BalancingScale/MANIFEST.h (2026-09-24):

// ============================================================
// MANIFEST.h — WatchTower Device Manifest
// This file is parsed by sync_manifests.py for the WatchTower dashboard.
// Keep all values as #define strings unless noted otherwise.
// ============================================================

#define DEVICE_NAME           "BalancingScale"
#define FIRMWARE_VERSION      "1.4.0"
#define BOARD_TYPE            "ESP32 (classic, CP210x USB bridge)"
#define ROOM                  "MermaidsTale"
#define DESCRIPTION           "RFID pendulum scale: two multi-tag RFID readers (spice pouches vs coins plates) match represented weights; servo indicates balance; publishes SOLVED on /status when all 5 pouch weights have been matched (M3 forwards as MermaidsTale/ScaleSolved)"

#define BUILD_STATUS          "stable"
#define CODE_HEALTH           "fair"
#define WATCHTOWER_COMPLIANCE "full"

// MQTT
#define BROKER_IP             "10.1.10.115"
#define BROKER_PORT           1883
#define HEARTBEAT_MS          300000

// Over-the-air updates (MANDATORY fleet protocol since 2026-09-22, added v1.4.0).
// Password = the Wi-Fi password (OTA_PASSWORD aliases WIFI_PASS in the sketch).
#define OTA_ENABLED           "yes"
#define OTA_HOSTNAME          "BalancingScale"      // = DEVICE_NAME
#define OTA_PORT              3232                  // classic ESP32

#define SUBSCRIBE_TOPICS      "MermaidsTale/BalancingScale/command"
#define PUBLISH_TOPICS        "MermaidsTale/BalancingScale/status, MermaidsTale/BalancingScale/log, MermaidsTale/BalancingScale/message, MermaidsTale/BalancingScale/message/servo, MermaidsTale/BalancingScale/message/Spice, MermaidsTale/BalancingScale/system/Spice/weight, MermaidsTale/BalancingScale/system/Coins/weight, MermaidsTale/BalancingScale/message/SuccessCount, MermaidsTale/BalancingScale/message/ServoState, MermaidsTale/BalancingScale/{Yeast|SugarCane|Vanilla|Molasses|Cloves}"
#define SUPPORTED_COMMANDS    "PING, STATUS (reply ... | IP:x.x.x.x | OTA:3232 | RSSI=x | UPxs), RESET, PUZZLE_RESET, SOLVE, HALTCOIN, HALTSPICE, REBOOTCOIN, REBOOTSPICE"

// Hardware
#define PIN_CONFIG            "SERVO=13 (was 35 = input-only on classic ESP32; moved by contractor 07-21), RFID1_RX=18, RFID1_TX=19 (spice plate), RFID2_RX=16, RFID2_TX=17 (coins plate)"
#define COMPONENTS            "2x multi-tag 125kHz RFID reader (0xF5-frame protocol, 5 tags max each), 1x indicator servo, 5 spice pouch tags, 8 coin tags"
#define KNOWN_QUIRKS          "Classic ESP32. Servo on GPIO13 (500-2400us, 100Hz; yay=155 nay=30 mid=70). Commands must not be retained. SOLVED on /status is deliberately not retained (would replay into fresh sessions). Per-pouch success topics + SuccessCount publish once per transition, not per scan. M3 AMT.xml event 162 sends PUZZLE_RESET on game reset. v1.4.0 OTA: wireless re-flash (hostname BalancingScale, port 3232, password = Wi-Fi) - arduino-cli upload --fqbn esp32:esp32:esp32 -p <board IP> --upload-field password=<Wi-Fi pw> Code/BalancingScale; IP is in every STATUS reply and the boot /log line. USB flashes go through the CP210x bridge (COM13 on 09-24, COM11 on 09-06 - port number moves)."

#define REPO_URL              "https://github.com/Alchemy-Escape-Rooms-Inc/Balancing-Scale"

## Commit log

2025-10-08 Added gerber file for the breakout pcb for the RFID.
2025-10-10 Removed unnecessary files and changed main code for UART COM rfids.
2025-10-15 Added Fusion360 and STL files for balancing scale plate.
    [RFID ID-12LA Plate v2.f3d, RFID ID-12LA Plate.stl]
2025-10-15 Added Fusion360 and STL files for the Balancing scale rfid housing.
    [RFID ID-12LA Housing.f3d, RFID ID-12LA Housing.stl, RFID ID-12LA Plate.f3d]
2025-10-20 Updated plate to have more clearance for the rfid mount area.
    [RFID ID-12LA Plate.f3d, RFID ID-12LA Plate.stl]
2025-10-21 Scale plate rfid mount file added.
    [RFID ID-12LA Plate Mount.stl]
2025-10-22 Updated 3D files for the plate rfid mount guides.
    [RFID ID-12LA Plate Mount.stl, RFID ID-12LA Plate.stl]
2025-10-22 Updated the gerber files:Fixed the orrientation of the headers on the board and removed the unnecessary components.
2025-10-23 Added a 2mm pitch version of the RFID breakout board gerber file.
2025-10-24 Fixed the breakout board headers alignment. They were mirrored.
2026-01-09 Added 3D files for coins, removed unnecessary files, and organized directories.
    [Coin 1.3mf, Coin 2.3mf, Coin Face 2.stl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]
2026-01-14 Added 2 new versions of the coins faces.
    [Coin Face 2.stl, Coin Face 3.stl, Coin Face 4.stl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]
2026-05-26 Creating save point. Developing storing verified ID function.
    [Coin Face 2.stl, Coin Face 3.stl, Coin Face 4.stl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]
2026-05-27 Removed unnecessary files. Got code to no errors.
    [BalancingScale.ino]
2026-06-04 Fixed the issue with storing ID tags.
    [BalancingScale.ino]
2026-06-06 Added the correct known ID tags for both the spices and coins.
    [BalancingScale.ino]
2026-07-10 v1.1.0: WatchTower MQTT protocol compliance + solve-signal fixes
    - FIX: puzzle could never signal solved by gameplay - checkSuccess had
    'puzzleSolved;' (a no-op) instead of setting it; now sets the flag and
    publishes SOLVED on /status, which M3's 'Balancing Scale Solved' event
    (AMT.xml event 25) matches to forward MermaidsTale/ScaleSolved
    - FIX: SOLVE command republished onto its own /command topic, creating an
    infinite MQTT echo loop; removed the echo
    - PING now answers PONG on /command (was /message, only visible to
    WatchTower via a legacy workaround)
    - STATUS returns full diagnostics (state, plate weights, matched count,
    IP, RSSI, uptime) instead of a bare READY
    - RESET: respo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
    [BalancingScale.ino, MANIFEST.h]
2026-08-27 v1.2.0: only write servo nay on actual mismatch (kills nay/yay flap + /message/servo spam while balanced)
    Claude-Session: https://claude.ai/code/session_01993hYuX6vQ5jLyDFWxQ7Qi
2026-09-06 v1.3.1: print IP/gateway/RSSI on serial after WiFi connect (flash-day diagnostics)
    Flashed to the classic ESP32 on COM11 2026-09-06. Board joined AlchemyGuest (10.1.10.201) but MQTT rc=-2
    because the desk PC Ethernet link (.115) was down; the serial IP print made that diagnosable in one read.
    Claude-Session: https://claude.ai/code/session_01DYjogHqvNDzZzRBaq4kbN4
2026-09-24 v1.4.0: ArduinoOTA (mandatory fleet protocol 2026-09-22), IP in boot line + STATUS
    - ArduinoOTA: hostname BalancingScale, port 3232, password = Wi-Fi (alias),
    begin() right after Wi-Fi, handle() every loop and inside the MQTT retry
    wait so a broker outage never blocks a wireless re-flash.
    - onStart parks the indicator servo and publishes "OTA update starting" on /log.
    - Boot /log line now carries IP:x.x.x.x OTA:3232 RSSI:x; STATUS reply uses
    the protocol's IP:x.x.x.x form and adds OTA:3232.
    - MANIFEST: OTA_ENABLED/OTA_HOSTNAME/OTA_PORT, version 1.4.0, board type
    pinned to classic ESP32 (CP210x bridge), OTA flash recipe in KNOWN_QUIRKS.
    Flashed over USB (COM13) 2026-09-24 16:22, boot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
    [BalancingScale.ino, MANIFEST.h]
2026-10-09 Add prop design files found outside the repo (cleanup 2026-10-09)
    Files the owner chose to keep from Downloads / OneDrive / Desktop; they were
    in no repo. Placed in 3DFiles/Imported-2026-10-09.
2026-10-18 v1.4.1: Wi-Fi join timeout + reboot, reboot if Wi-Fi lost mid-run
    A failed first Wi-Fi join spun forever (board lit, silent on MQTT) and a
    mid-run Wi-Fi drop made connectMQTT spin forever. Both now reboot after 20s.
2026-10-18 v1.4.2: needle actually swings to NAY on a wrong answer
    servoState was a bool that started as 'nay' while boot parks the needle at
    center, so the first mismatch looked like 'already nay' and the servo never
    moved. Now tri-state (center/yay/nay); empty plate = center, both plates
    loaded and unequal = nay, equal = yay. PUZZLE_RESET parks at center.
2026-10-18 v1.4.3: center needle 70 -> 92 (was in nay territory) + SERVO_TEST:<angle> tuning command
2026-10-18 v1.4.4: center needle 92 -> 97 (tuned by eye on the prop)
2026-10-18 v1.4.5: center needle approaches from the yay side to 1519us (96.5 deg) to beat linkage slack; SERVO_US:<us> tuning command
2026-10-18 v1.4.7: needle centers whenever a plate reads nothing
    - rewrite tag-removal check: old shared mismatch counter could drop a tag
    still on the plate and left lifted tags for extra scans
    - reader silent 3 scans in a row = plate empty (needle centers)
    - keep scanning after solve so emptied plates still return needle to center
2026-10-19 v1.4.8: loop watchdog + MQTT-dead reboot + per-tag 3-miss removal
    - 30 s task watchdog on the loop (fed in loop, MQTT retry, OTA progress):
    board froze 10-18 19:00 and 10-19 11:32 with Wi-Fi up, no MQTT/OTA
    - reboot if MQTT unreachable 60 s with Wi-Fi up
    - boot /log line carries UP + RESET reason (TASK_WDT = froze)
    - a stored tag is only dropped after 3 consecutive scans without it:
    coin reader skipping a tag for one scan swung the needle back and forth
2026-10-25 v1.4.9: readResponse always drains the UART (full buffer + talking reader spun until TASK_WDT reboot)
    Diagnosis from Merlin's weekly fault review 2026-10-25. Compiled, not flashed.
2026-10-31 README: describe the real v1.4.9 ESP32 board, not the old Arduino Nano build
    Controller, readers, pins, puzzle values, needle logic, MQTT topics, self-recovery and OTA now match BalancingScale.ino. Image links fixed to Docs/res.
2026-11-06 v1.5.0: resync on the reader frame header instead of "Bad frame." every second
    The tag-count and UID reads now find the F5 len ~len frame anywhere in the
    reply rather than requiring it at byte 0, so stray leading bytes no longer
    throw the read away (each bad frame also counted as a miss toward removing
    tags). A reply with no frame at all is reported at most once a minute per
    plate, naming the plate and dumping the bytes.
2026-11-06 v1.5.1: RFIDDIAG command reports every reader reply for 5 min
    Send RFIDDIAG on /command and each plate's reply (OK tags=N, SILENT, or
    BAD with a hex dump) goes to /message/diag with no rate limit, so a wire
    can be wiggled while watching. RFIDDIAG_OFF ends it early.
